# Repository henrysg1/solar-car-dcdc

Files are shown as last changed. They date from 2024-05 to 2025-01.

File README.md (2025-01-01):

# DC-DC Converter for Solar Car



## Overview

This repository contains the design files for a DC-DC converter used in the University of Nottingham's solar race car. The converter steps down the battery voltage from 135V to 12V, which is essential for powering various low-voltage components in the vehicle.

## Features

- **Input Voltage:** 135V
- **Output Voltage:** 12V
- **Output Current:** Up to 50A
- **Efficiency:** > 90%
- **Protection:** Overvoltage, Overcurrent, Thermal Shutdown
- **Compact PCB Design**

## Status

The PCB revision in this repository has been manufactured and succesfully tested and implemented in the solar car, verifying that the system works as intended.

## Getting Started

### Prerequisites

To work with the design files, you will need:

- [KiCad](https://kicad.org/) for schematic and PCB design. **Important Note: For this project, a Nightly Development Build of KiCAD has been used (6.99). The project will not work on a Stable Version release (6.00)**

### Usage

1. Clone the repository:
   ```bash
   git clone https://github.com/yourusername/dcdc-converter-solar-car.git
   cd dcdc-converter-solar-car
   ```
2. Include the component files in the KiCAD project (in the 'Component Files' folder)
3. Open the schematic file (dcdc_converter.sch) in KiCad.
4. Open the PCB layout file (dcdc_converter.kicad_pcb) in KiCad.

## Schematic



The schematic for the DC-DC converter is designed to step down the voltage from 135V to 12V. Here are the key sections and components:

### Input Section
- **J2, J3 (Connectors):** These connectors receive the high voltage (135V) input.
- **F1, F2 (5A Fuses):** Provide overcurrent protection for the high voltage input.

### Relay Control
- **K1 (Relay):** This relay enables or disables the DC-DC converter based on an external switch connected through IPL1.
- **D1 (Diode):** Acts as a flyback diode for the relay coil, protecting against voltage spikes.

### Primary Conversion Stage
- **L1, L2 (1µH Inductors):** Form LC filters along with C1 and C2 to smooth the input voltage.
- **R1, R2 (1Ω Resistors):** Used for current sensing in the primary stage.

### DC-DC Converter Modules
- **PS1, PS2 (DCM3623T5N13B4T00):** These modules handle the main conversion from high to low voltage. They include control and feedback components:
  - **R5, R6 (510Ω, 50kΩ Resistors)**
  - **RV1, RV2 (250kΩ Potentiometers)**
  - **D3, D4 (LTST-C193KRKT-5A Diodes)**

### Output Section
- **L3, L4 (0.15µH Inductors):** Further filter the output voltage.
- **C3, C4 (1000µF Capacitors):** Stabilize the output voltage.
- **F4, F5 (25A Fuses):** Provide overcurrent protection for the output.
- **J4 (Output Connector):** The connector for accessing the stepped-down 12V output.

This design ensures efficient voltage conversion with necessary protections for both input and output stages.

## PCB Layout



The PCB layout is designed to maximise efficiency and handle high current traces. Key considerations include:

- Trace Widths: Sized appropriately for current handling.
- Component Placement: Optimised for thermal management and isolating voltages.
- Ground Plane: Ensures low impedance return paths.

## License
This project is licensed under the MIT License. See the LICENSE file for details.

## Acknowledgments
University of Nottingham Solar Race Team \
KiCad Community

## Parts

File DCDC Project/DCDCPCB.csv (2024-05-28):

Id | Designator | Package | Quantity | Designation | Supplier and ref
1 | R2,R1 | R_Axial_DIN0207_L6.3mm_D2.5mm_P10.16mm_Horizontal | 2 | 1
2 | F1,F2 | FuseHolder8A | 2 | 8A
3 | PS2,PS1 | DCM3623TA5N13B4T00Heatsink | 2 | DCM3623TA5N13B4T00
4 | D3 | TO-247-3_VerticalSINK | 1 | D_Schottky_x2_KCom_AKA
5 | C1,C2 | MKP1848C52080JK2 | 2 | 2uF
6 | R5,R6 | R_Axial_DIN0207_L6.3mm_D2.5mm_P10.16mm_Horizontal | 2 | 301
7 | L3,L4 | 0.15UInductor | 2 | 0.15uH
8 | C4,C3 | CP_Radial_D12.5mm_P5.00mm | 2 | 1000uF
9 | D1 | D_DO-35_SOD27_P7.62mm_Horizontal | 1 | D
10 | D2 | LED_D5.0mm | 1 | LED
11 | K1 | Micro_Relay_V23086C1001A403 | 1 | RELAY_SPDT
12 | L1,L2 | 1uHInductor | 2 | 1uH
13 | R3 | R_Axial_DIN0207_L6.3mm_D2.5mm_P10.16mm_Horizontal | 1 | 470
14 | R4 | R_Axial_DIN0207_L6.3mm_D2.5mm_P10.16mm_Horizontal | 1 | 50k
15 | JP1,JP2 | Jumper | 2 | Jumper
16 | J6 | SAMTEC_MPT-04-6.30-XX-X-V | 1 | MPT-02
17 | J1,J2,J3,J4,J5 | SAMTEC_IPL1-102-01-L-S-K | 5 | IPL1
18 | F3 | FUSE_3555-2 | 1 | 3555-2

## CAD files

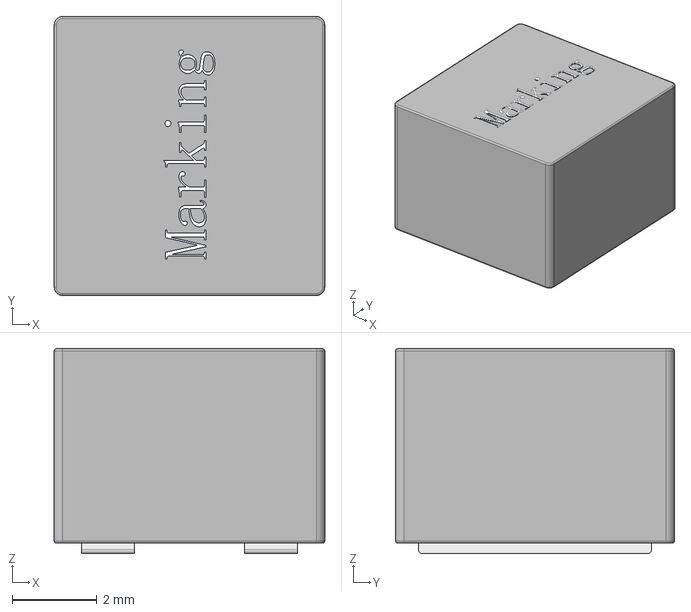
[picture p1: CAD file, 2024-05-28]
Component Files/3D Shapes/SRP6050CA-1R0M.stp
6.40 x 6.60 x 4.86 mm

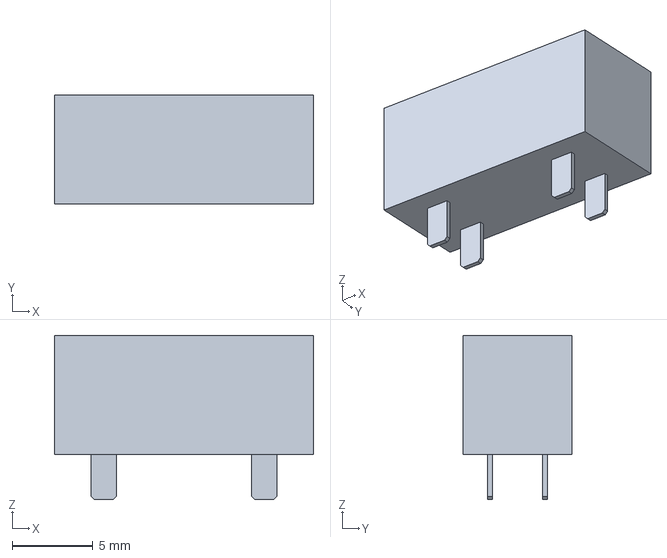
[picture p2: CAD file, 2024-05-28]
Component Files/3D Shapes/Keystone_-_3568.step
16.0 x 6.73 x 10.2 mm

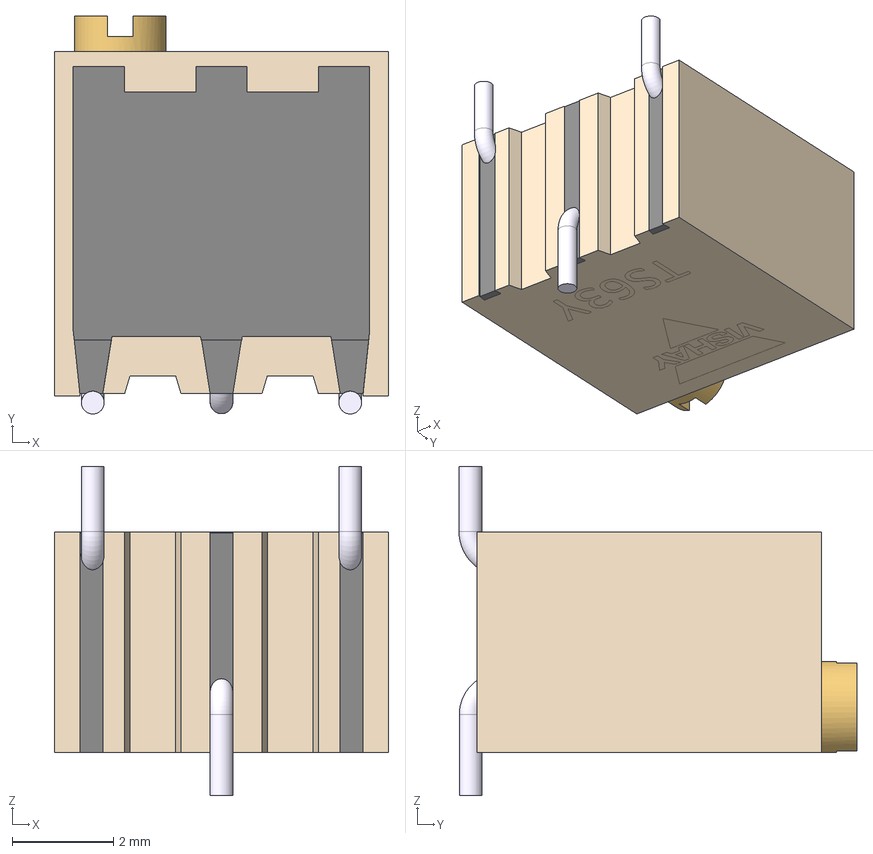
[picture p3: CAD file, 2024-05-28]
Component Files/3D Shapes/TS63Y-VISHAY.stp
6.60 x 7.85 x 6.50 mm
3926550_oa_0
3926650_oa_1
Scellement TS6XY_oa_2
crochet lateral SXY _oa_3
crochet central SXY _oa_4
crochet lateral SXY _oa_5
Intérieur TS63

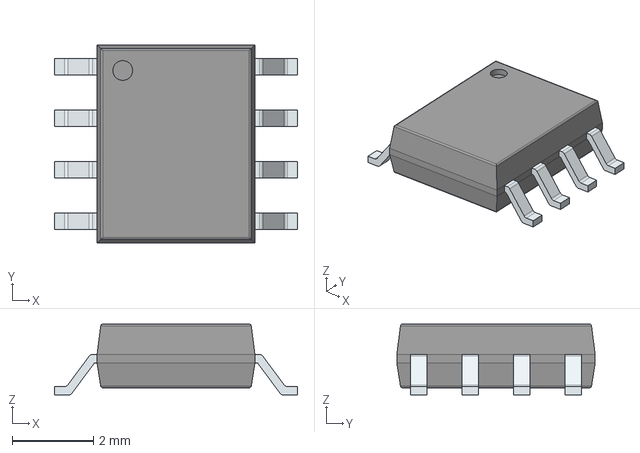
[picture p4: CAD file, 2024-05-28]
Component Files/3D Shapes/NE555DR.stp
6.00 x 4.90 x 1.75 mm
PinsArrayLR

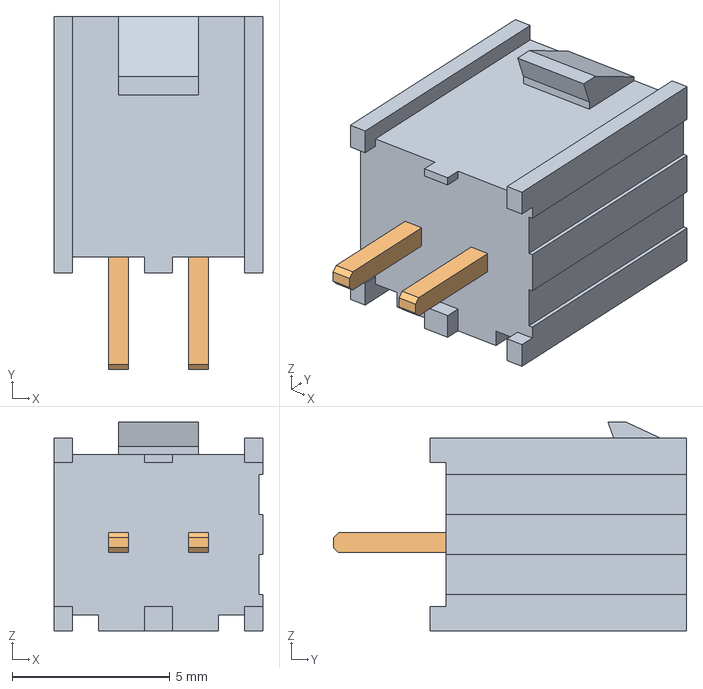
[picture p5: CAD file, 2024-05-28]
Component Files/3D Shapes/IPL1-102-01-L-S-K.step
6.60 x 11.2 x 6.60 mm
_IPL1-102-01-S-K_HDR
_T-1S64-01-02-S

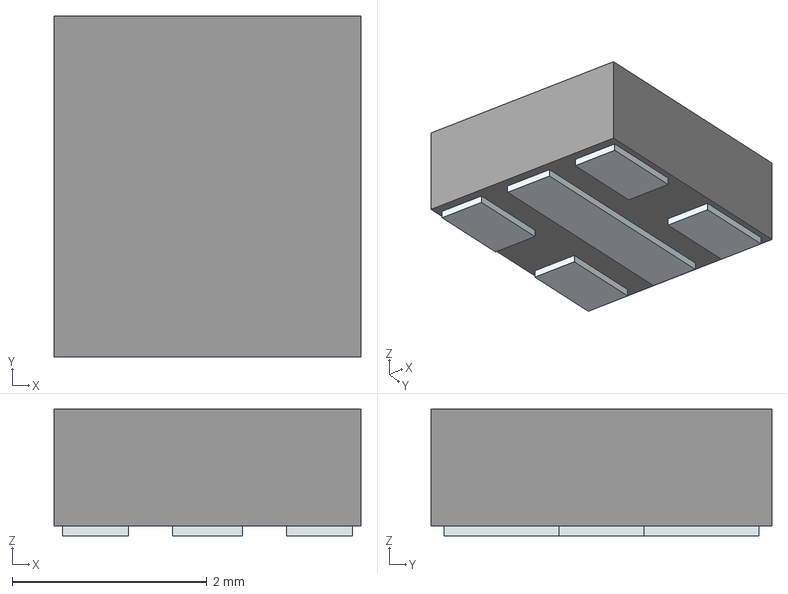
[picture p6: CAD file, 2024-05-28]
Component Files/3D Shapes/MLESRD-A1-0000-000W01.stp
3.15 x 3.50 x 1.30 mm
Pins

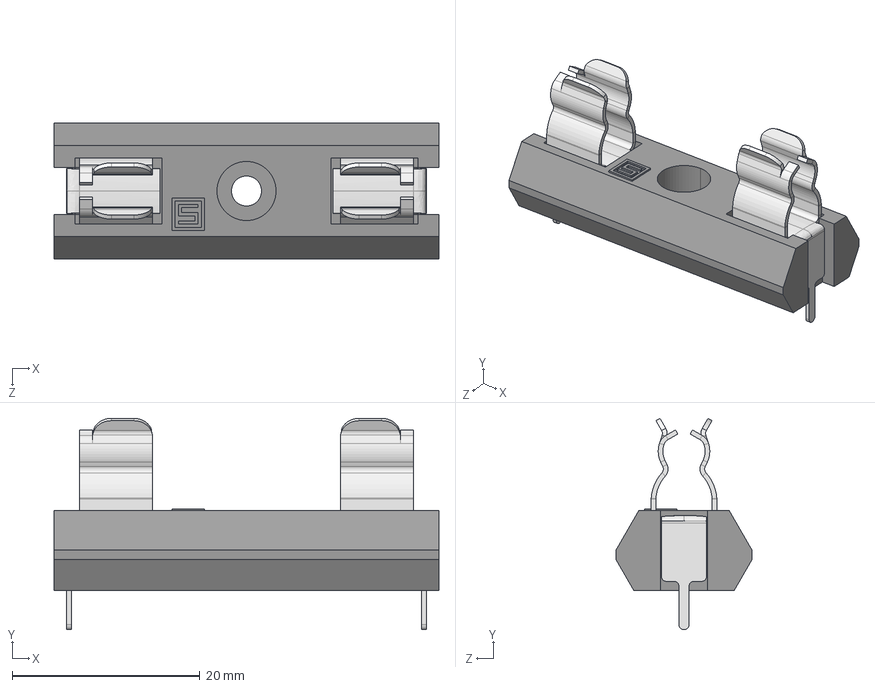
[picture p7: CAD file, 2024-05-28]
Component Files/3D Shapes/E_0100.3954_03.STEP
41.0 x 22.5 x 14.5 mm

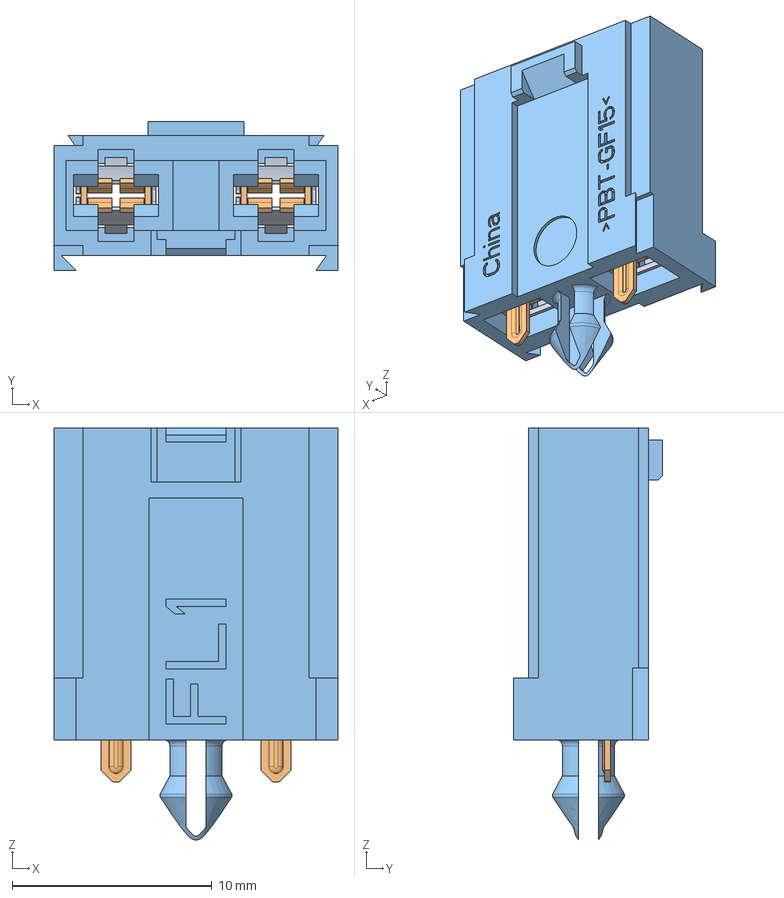
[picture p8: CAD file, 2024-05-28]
Component Files/3D Shapes/178.6764.0001.stp
14.2 x 7.45 x 20.6 mm
10000043873amo000_a x 2
10000043874amo000_a x 2
10000043872amo000_a

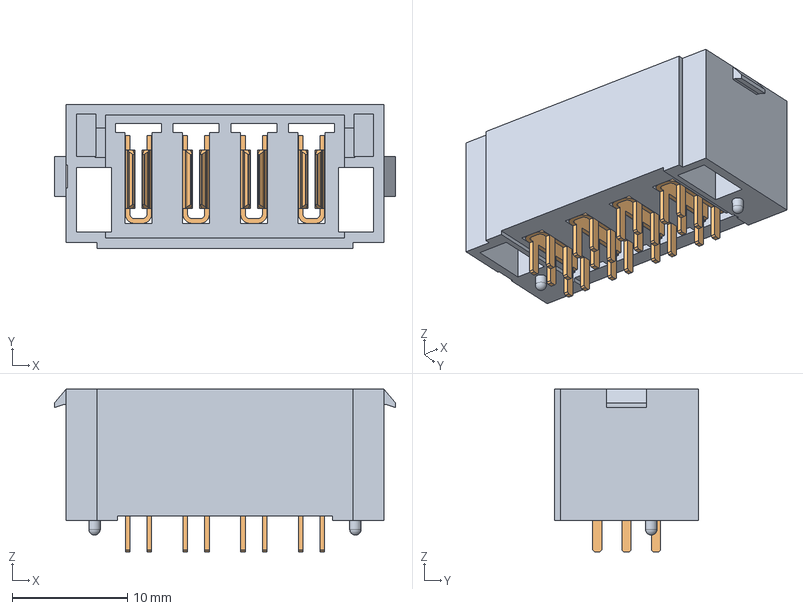
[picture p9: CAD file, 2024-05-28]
Component Files/3D Shapes/MPT-04-6.30-XX-X-V.step
29.6 x 12.4 x 14.1 mm
_MPT04-SDterminal1
_MPT0401pins3

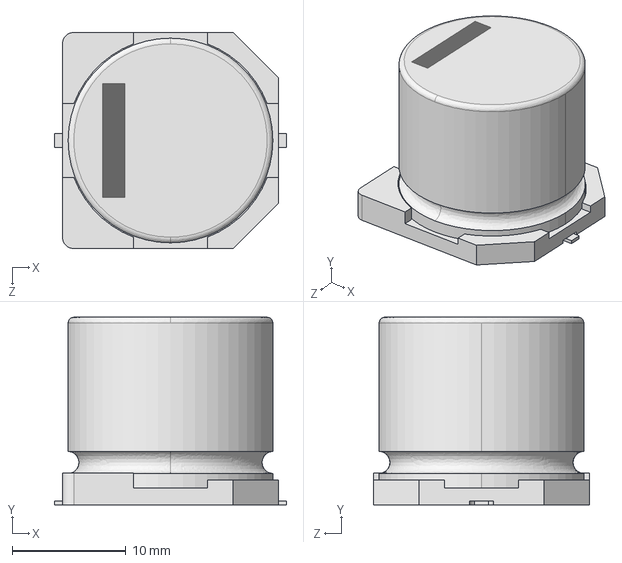
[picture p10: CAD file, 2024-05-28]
Component Files/3D Shapes/EEVTG1E102M.step
20.4 x 16.5 x 19.0 mm

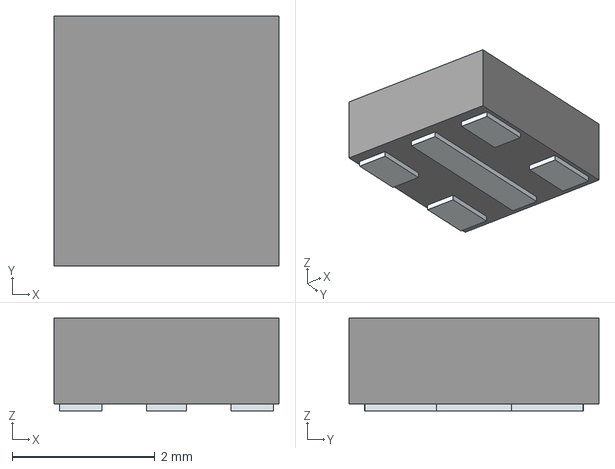
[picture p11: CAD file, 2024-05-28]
Component Files/3D Shapes/MLESGN-A1-0000-000101.stp
3.15 x 3.50 x 1.30 mm
Pins

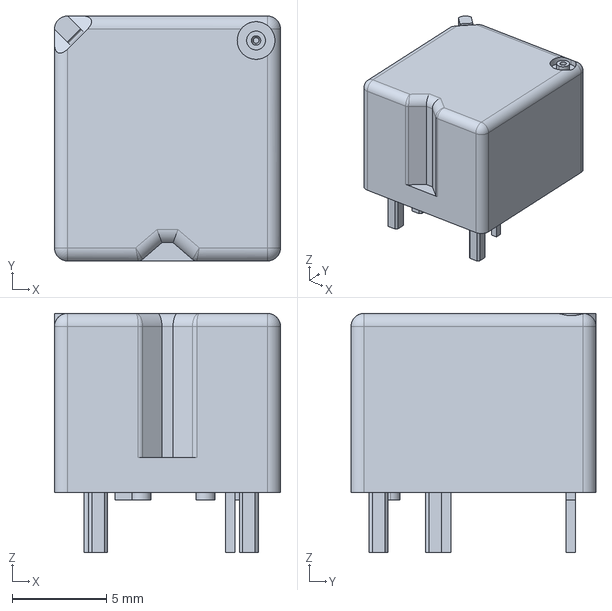
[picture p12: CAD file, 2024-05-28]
Component Files/3D Shapes/c-1393280-6-b1-3d.stp
12.0 x 13.0 x 12.7 mm

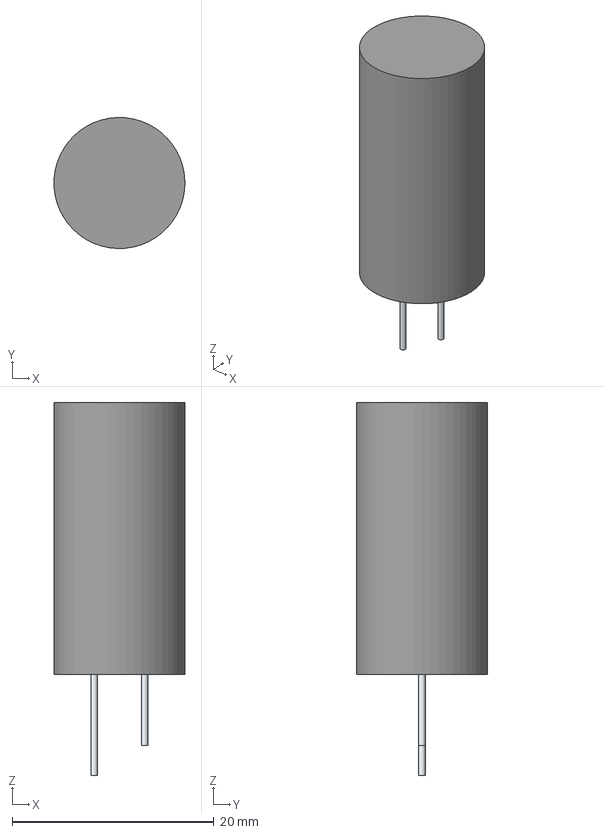
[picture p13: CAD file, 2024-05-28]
Component Files/3D Shapes/EEUFM1V102.stp
13.0 x 13.0 x 37.0 mm
SimpleBody
Pin1
Pin2

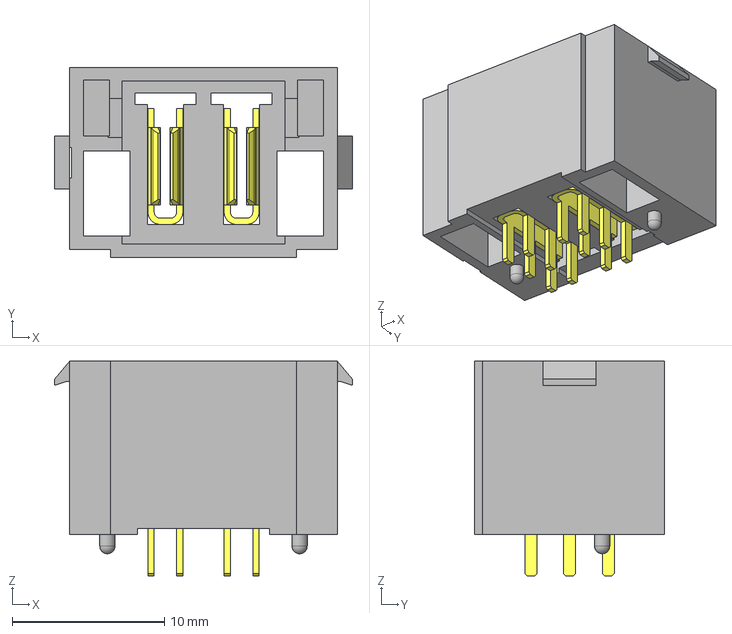
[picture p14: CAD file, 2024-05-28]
Component Files/3D Shapes/MPT-02-6.30-01-T-V.stp
19.6 x 12.4 x 14.1 mm
_MPT02-SDterminal1
_MPT0201pins3

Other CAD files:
Component Files/3D Shapes/SRP7028AA-R15Y.stp
Component Files/3D Shapes/MKP1848C52080JK2.stp
Component Files/3D Shapes/39824.STEP
Component Files/3D Shapes/EEV-TG1E102M.stp
Component Files/3D Shapes/TPS92612QDBVRQ1.stp
Component Files/3D Shapes/V23086C1001A403_1393280-6.stp

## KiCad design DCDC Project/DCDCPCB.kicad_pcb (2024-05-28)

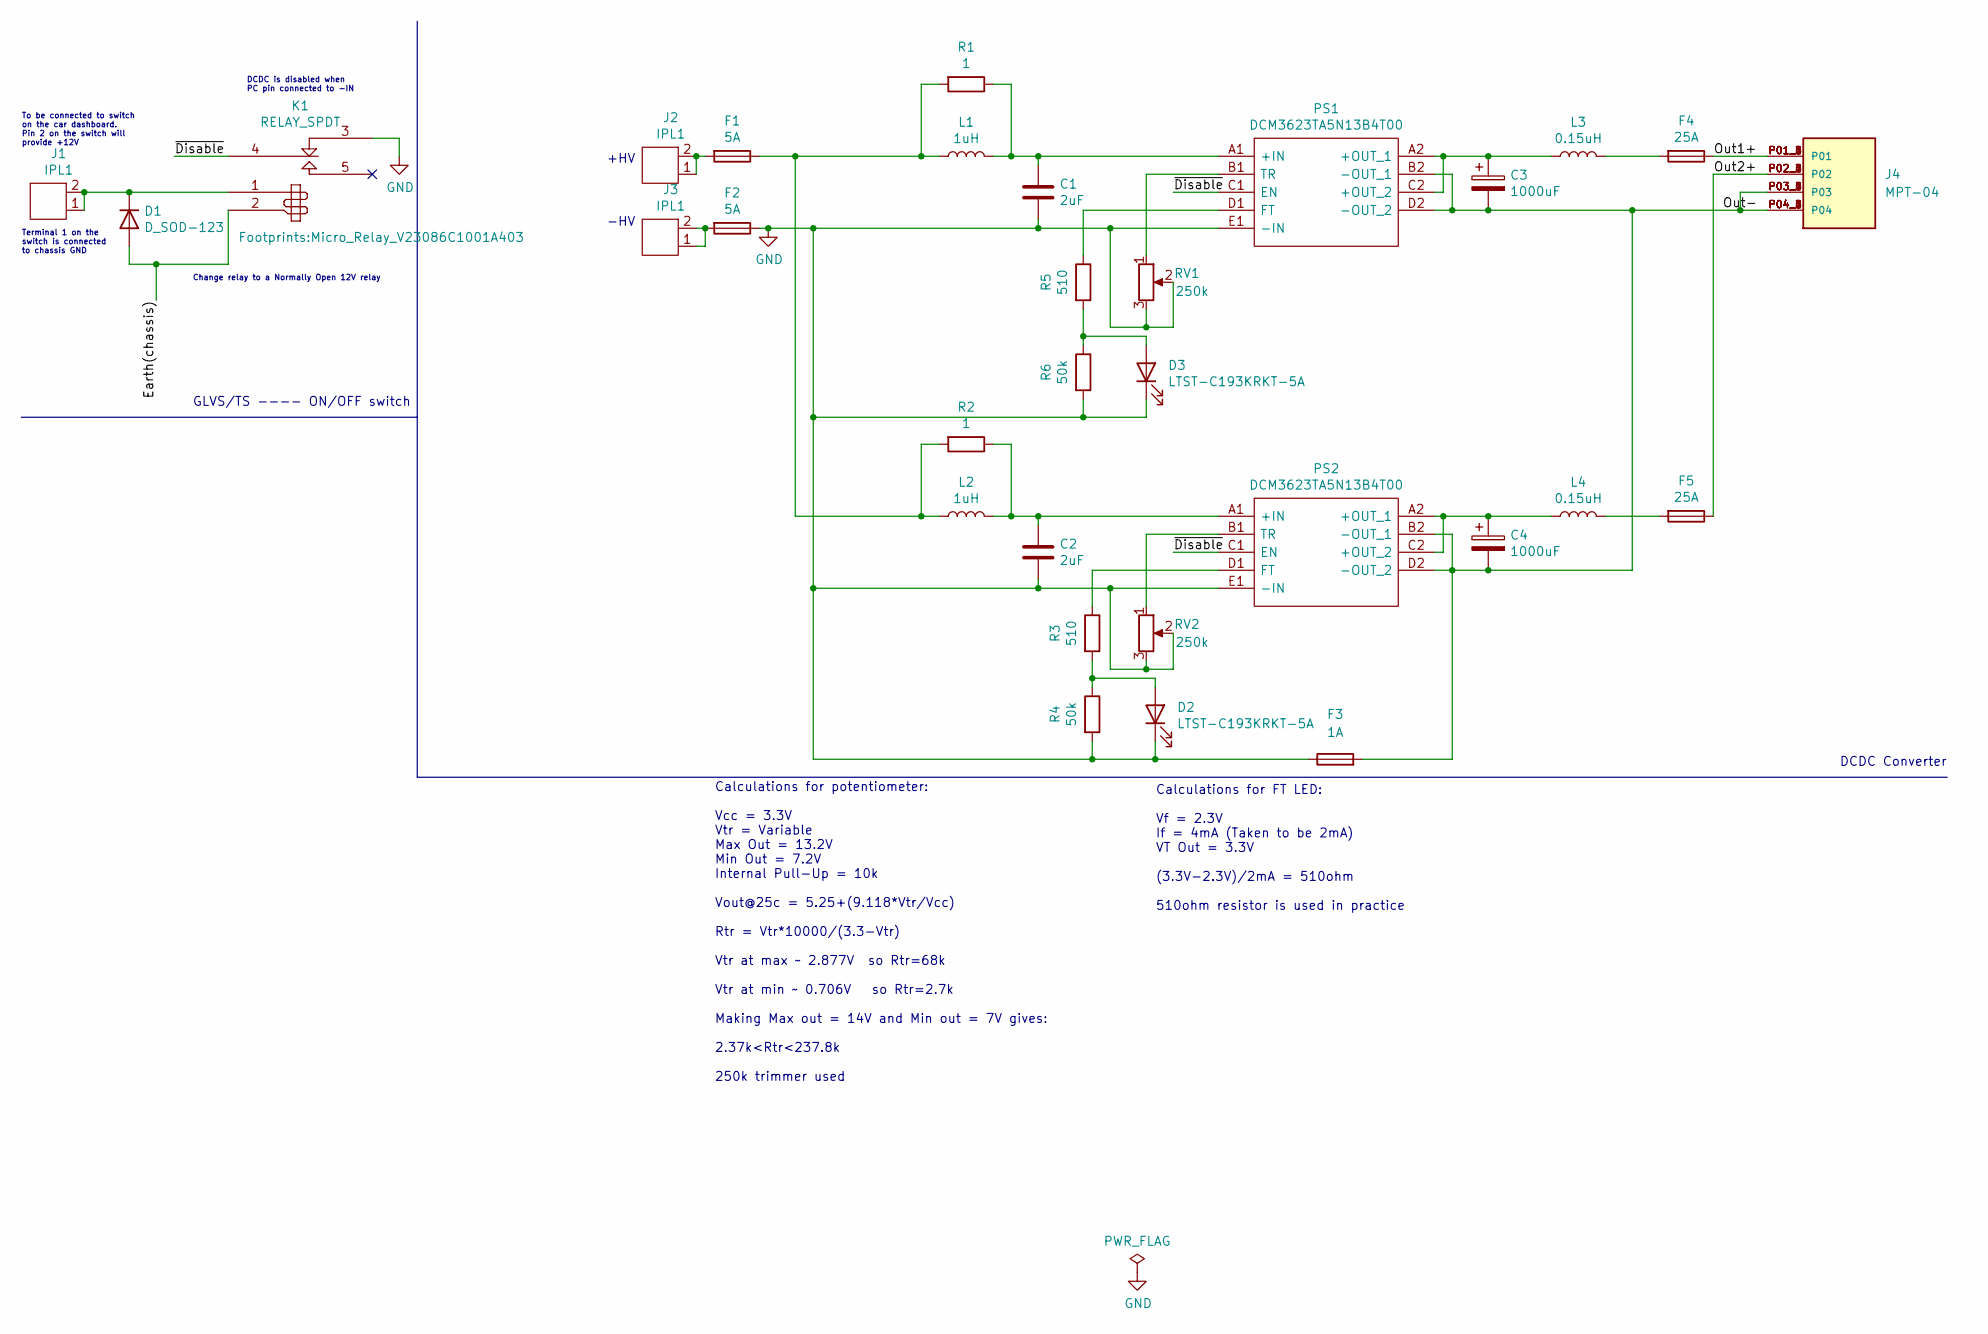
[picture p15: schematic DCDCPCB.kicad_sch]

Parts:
C1, C2: 2uF; C_2220_5650Metric
C3, C4: 1000uF; CAP_EEVTG1E102M
D1: D_SOD-123
D2, D3: LTST-C193KRKT-5A; LED_0603_1608Metric
F1, F2: 5A; PCB_Fuse_Holder_MC_69_0013
F3: 1A; D_1206_3216Metric
F4, F5: 25A; 3568
J1, J2, J3: IPL1; SAMTEC_IPL1-102-01-L-S-K
J4: MPT-04; SAMTEC_MPT-04-6.30-XX-X-V; PARTREV E
K1: RELAY_SPDT; Micro_Relay_V23086C1001A403
L1, L2: 1uH; 1uHInductor
L3, L4: 0.15uH; 0.15UInductor
PS1, PS2: DCM3623TA5N13B4T00; DCM3623TA5N13B4T00Heatsink; Manufacturer_Part_Number DCM3623TA5N13B4T00; Mouser Part Number 492-DCM3623TA513B4T0
R1, R2: 1; R_1206_3216Metric
R3, R5: 510; R_0603_1608Metric
R4, R6: 50k; R_0603_1608Metric
RV1, RV2: 250k; TS63Y254KT20

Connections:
/Earth(chassis): D1.2 (A), K1.2
/Out1+: F4.1, J4.P01_1 (P01), J4.P01_2 (P01), J4.P01_3 (P01), J4.P01_4 (P01), J4.P01_5 (P01), J4.P01_6 (P01)
/Out2+: F5.1, J4.P02_1 (P02), J4.P02_2 (P02), J4.P02_3 (P02), J4.P02_4 (P02), J4.P02_5 (P02), J4.P02_6 (P02)
/Out-: C3.2, C4.2, F3.2, J4.P03_1 (P03), J4.P03_2 (P03), J4.P03_3 (P03), J4.P03_4 (P03), J4.P03_5 (P03), J4.P03_6 (P03), J4.P04_1 (P04), J4.P04_2 (P04), J4.P04_3 (P04), J4.P04_4 (P04), J4.P04_5 (P04), J4.P04_6 (P04), PS1.B2 (-OUT_1), PS1.D2 (-OUT_2), PS2.B2 (-OUT_1), PS2.D2 (-OUT_2)
/~Disable: K1.4 (C1), PS1.C1 (EN), PS2.C1 (EN)
GND: C1.2, C2.2, D2.1 (K), D3.1 (K), F2.1, F3.1, K1.3 (R1), PS1.E1 (-IN), PS2.E1 (-IN), R4.2, R6.2, RV1.2, RV1.3, RV2.2, RV2.3
unnamed: D1.1 (K), J1.1, J1.2, K1.1
unnamed: D2.2 (A), R3.2, R4.1
unnamed: D3.2 (A), R5.2, R6.1
unnamed: F1.1, L1.1, L2.1, R1.2, R2.2
unnamed: F1.2, J2.1, J2.2
unnamed: F2.2, J3.1, J3.2
unnamed: F4.2, L3.2
unnamed: F5.2, L4.2
unnamed: C1.1, L1.2, PS1.A1 (+IN), R1.1
unnamed: C3.1, L3.1, PS1.A2 (+OUT_1), PS1.C2 (+OUT_2)
unnamed: PS1.D1 (FT), R5.1
unnamed: PS1.B1 (TR), RV1.1
unnamed: C2.1, L2.2, PS2.A1 (+IN), R2.1
unnamed: C4.1, L4.1, PS2.A2 (+OUT_1), PS2.C2 (+OUT_2)
unnamed: PS2.D1 (FT), R3.1
unnamed: PS2.B1 (TR), RV2.1

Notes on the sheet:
+HV
Calculations for FT LED: Vf = 2.3V If = 4mA (Taken to be 2mA) VT Out = 3.3V (3.3V-2.3V)/2mA = 510ohm 510ohm resistor is used in practice
Calculations for potentiometer: Vcc = 3.3V Vtr = Variable Max Out = 13.2V Min Out = 7.2V Internal Pull-Up = 10k Vout@25c = 5.25+(9.118*Vtr/Vcc) Rtr = Vtr*10000/(3.3-Vtr) Vtr at max ~ 2.877V so Rtr=68k Vtr at min ~ 0.706V so Rtr=2.7k Making Max out = 14V and Min out = 7V gives: 2.37k<Rtr<237.8k 250k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
Terminal 1 on the switch is connected to chassis GND
Change relay to a Normally Open 12V relay
To be connected to switch on the car dashboard. Pin 2 on the switch will provide +12V
DCDC is disabled when PC pin connected to -IN
DCDC Converter
-HV
GLVS/TS ---- ON/OFF switch

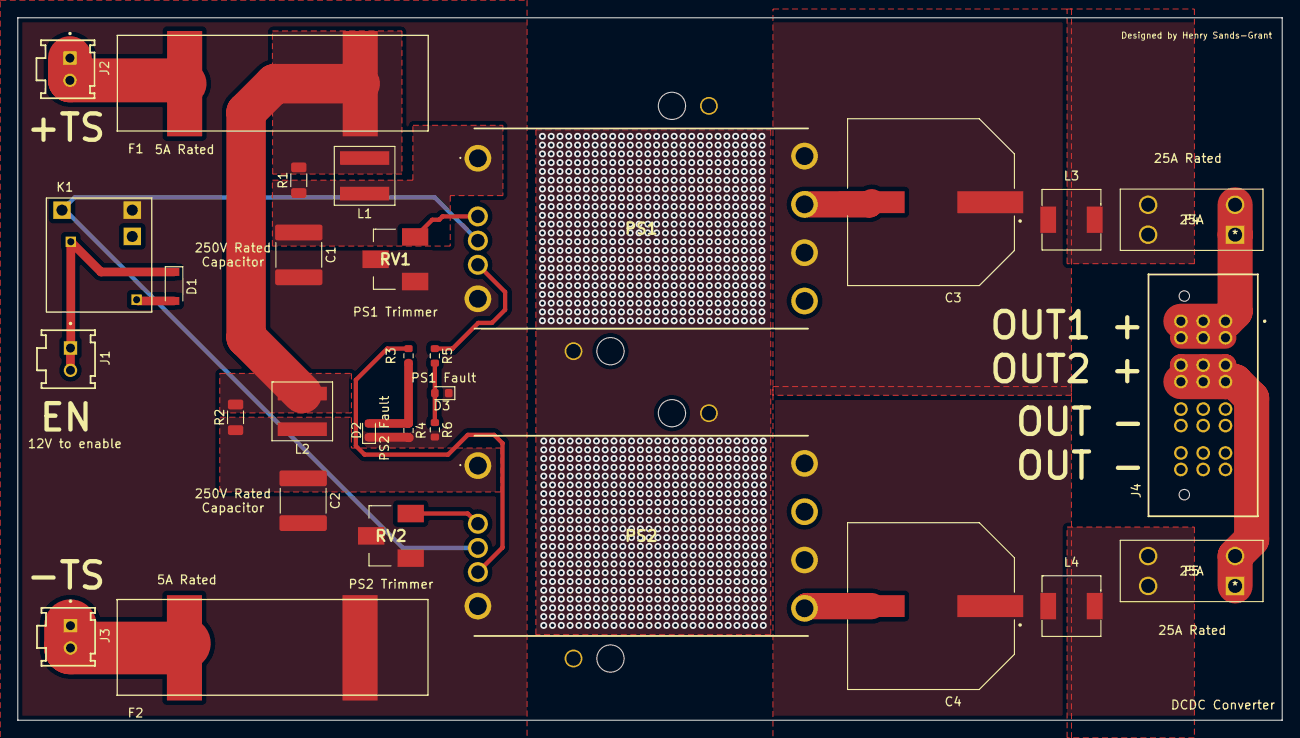
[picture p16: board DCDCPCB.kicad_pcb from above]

Board: 2 copper layers, 144.0 x 80.0 mm, 31 parts (1 on the bottom side), 22 nets.

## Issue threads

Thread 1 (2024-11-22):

Enter the highest voltage doubt

kunluntaishang, 2024-11-22:
I looked up the data sheet of the dcdc chip you are using, and it seems that only 154V can be input at most, how is the 600V you described calculated

henrysg1, 2024-11-26:
Hi @kunluntaishang,

You are absolutely right, and it seems as though I have mislabeled the HV as 600V, when it was actually 135V for our car. This was an old project that I recently uploaded to GitHub so I will update the README and add the voltage in the schematic for clarity's sake.

Thanks for spotting this.

Closed 2025-01-01.

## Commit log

2024-05-28 Updating file directories
    [DCDCPCB.csv, DCDCPCB.kicad_pcb, DCDCPCB.kicad_sch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]
2025-01-01 Updating schematic for voltage
    [DCDCPCB.kicad_sch]

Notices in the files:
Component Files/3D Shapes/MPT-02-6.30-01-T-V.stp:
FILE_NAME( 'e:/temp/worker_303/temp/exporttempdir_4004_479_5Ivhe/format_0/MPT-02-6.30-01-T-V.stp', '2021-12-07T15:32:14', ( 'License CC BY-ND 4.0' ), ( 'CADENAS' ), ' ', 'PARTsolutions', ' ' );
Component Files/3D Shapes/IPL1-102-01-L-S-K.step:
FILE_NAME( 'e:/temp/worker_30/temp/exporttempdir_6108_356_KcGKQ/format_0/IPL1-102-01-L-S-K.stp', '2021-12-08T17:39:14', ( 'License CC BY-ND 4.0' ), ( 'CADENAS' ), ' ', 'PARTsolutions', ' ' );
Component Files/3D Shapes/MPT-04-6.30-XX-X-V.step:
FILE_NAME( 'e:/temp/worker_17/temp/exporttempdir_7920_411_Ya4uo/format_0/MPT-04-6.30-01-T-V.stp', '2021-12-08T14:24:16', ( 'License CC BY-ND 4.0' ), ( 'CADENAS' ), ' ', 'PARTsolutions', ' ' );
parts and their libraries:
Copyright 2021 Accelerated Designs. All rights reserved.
